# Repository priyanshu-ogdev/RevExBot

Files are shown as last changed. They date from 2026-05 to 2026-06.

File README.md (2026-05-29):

<div align="center">

# 🤖 RevExBot – Humanoid Robot Production Infrastructure


[]()
[]()
[]()

A complete, open-source infrastructure for designing, training, and deploying a full‑body humanoid robot with integrated dexterous hands. From CAD to reinforcement learning to physical fabrication.

[Documentation](#-documentation) • [Quick Start](#-quick-start) • [Architecture](#-architecture) • [Contributing](#-contributing)

</div>

---

## 📋 Table of Contents

- [Overview](#-overview)
- [Architecture](#-architecture)
- [Repository Structure](#-repository-structure)
- [Documentation](#-documentation)
- [Quick Start](#-quick-start)
- [Phase Workflows](#-phase-workflows)
- [Contributing](#-contributing)
- [License](#-license)

---

## 🎯 Overview

**RevExBot** is a production-grade infrastructure for autonomous humanoid robot development, implementing a **three-phase workflow** that bridges simulation, training, and physical deployment:

| Phase | Focus | Status | Timeline |
|---|---|---|---|
| **Phase 1** | Hardware design & simulation modelling | ✅ Complete | Foundation |
| **Phase 2** | Reinforcement learning training (Isaac Lab) | ⏳ In Progress | Training |
| **Phase 3** | Physical fabrication, assembly & deployment | 📦 Ready | Production |

This repository is fully self-contained with CAD files, electrical schematics, trained policies, and deployment scripts for edge compute (Radxa CM5).

---

## 🏗️ Architecture

```
RevExBot Infrastructure
├── assets/               CAD, meshes, URDF/Xacro kinematic models
├── hardware/
│   ├── electrical/       KiCad PCB design, wiring harnesses
│   └── mechanical/       STEP files, fabrication manifests
├── revex_ext/            Isaac Lab extension (RL training pipeline)
└── output/               Compiled URDF and deployment artifacts
```

**Key Technologies:**
- 🎮 **Isaac Lab** – Physics simulation and RL training
- 🧠 **RL-Games / SKRL** – Multi-domain expert training
- 🔧 **KiCad** – PCB design and electrical control
- 🤖 **URDF/Xacro** – Kinematic robot description
- 🚀 **Radxa CM5** – Edge compute for 200Hz control loop

---

## 📁 Repository Structure
### Top-Level Directories

| Directory | Purpose | Phase |
|---|---|---|
| **`assets/`** | Visual & collision meshes, URDF/Xacro kinematic models | 1, 2, 3 |
| **`build/`** | Build automation scripts (URDF compilation, format conversion) | 2, 3 |
| **`hardware/`** | Electrical (KiCad PCB) and mechanical (CAD/STEP) designs | 3 |
| **`isaac_lab_config/`** | Isaac Lab environment configurations | 2 |
| **`output/`** | Compiled URDF and deployment-ready artifacts | 2, 3 |
| **`revex_ext/`** | Isaac Lab extension with full RL training pipeline | 2 |

---

### 📂 Directory Deep-Dive

#### 🎨 `assets/` – Kinematic Models & Meshes

Contains simulation-ready meshes and the robot's complete kinematic description.

| Subfolder | Contents | Use Case |
|---|---|---|
| `meshes/` | `.STL` collision and visual geometry for all body links and hands | Simulation, physics, 3D rendering |
| `xacro/` | `master_assembly.xacro`, `faive_hand.xacro` – production URDF macros | Kinematic chain definition, joint configuration |
| `mjcf/` | MuJoCo XML format (alternative to URDF) | Direct MuJoCo simulation |
| `urdf/` | Legacy URDF files (kept for reference) | Backward compatibility |

**Phase 2 Usage:** Isaac Lab imports these directly via the asset importer.  
**Phase 3 Usage:** Same meshes serve as visual reference for physical assembly.

---

## 🔨 `build/` – Code Generation & Automation

Helper scripts for asset compilation and format conversion.

| Script | Purpose | Output |
|---|---|---|
| `compile_urdf.py` | Converts Xacro → flat URDF | `output/revexbot.urdf` |
| `convert_to_usd.bat` | Batch format conversion for Omniverse | USD native format |
| `generate_fabrication.py` | Auto-generates BOM from STEP file tree | `FABRICATION_MANIFEST.json` |

**When to run:**
- Before Phase 2: Any changes to xacro files
- Before Phase 3: Fabrication manifest updates

---

## ⚡ `hardware/` – Electrical & Mechanical Design

All electrical design assets for the physical robot.
electrical/
├── README.md
├── motion_control/
│   ├── mcb-io.dts # Device tree overlay (Radxa CM5 SPI/CAN)
│   ├── board/ # KiCad project – carrier board for Radxa CM5
│   └── scripts/
│       └── serial.sh # Serial port init script
└── wiring/
    ├── wiring.svg # Wiring harness diagram
    └── wiring.yaml # Harness mapping (pin-to-pin)

**Electrical** (`hardware/electrical/`)  
- `motion_control/board/` – Full KiCad PCB project for Radxa CM5 carrier board
- `motion_control/scripts/` – Linux device tree overlays and init scripts
- `wiring/` – Harness documentation and pin-to-pin mappings

**Mechanical** (`hardware/mechanical/`)  
- `RVX1/` – Master CAD assembly and sub-assemblies (grouped 100–700)
- `FABRICATION/` – Per-material fabrication packages (CNC, MJF, SLM, OTS)
- `FABRICATION_MANIFEST.json` – Complete BOM with part numbers and vendors

**Phase 2:** Not used (simulation only).  
**Phase 3:** Primary artifact for fabrication workflow.

---

## 🧠 `revex_ext/` – Isaac Lab RL Training Extension

The heart of Phase 2 training. Full out-of-tree extension with:
- **Environments:** Locomotion, agile recovery, tri-domain experts (combat/dance/precision)
- **Training scripts:** Multi-phase RL pipeline with expert/router/finetune modes
- **Policy export:** ONNX conversion for edge deployment

[See `revex_ext/README.md`](revex_ext/README.md) for detailed training workflows.

---

## 📤 `output/` – Compiled Deployment Artifacts

| File | Purpose | Generated By |
|---|---|---|
| `revexbot.urdf` | Flat URDF for Isaac Lab / MuJoCo | `build/compile_urdf.py` |

**Phase 2:** Not used – simulation runs entirely in software.  
**Phase 3:**
- Send Gerber files (generated from `board/`) to a PCB fab (JLCPCB/PCBWay).
- Flash `mcb-io.dts` and run `serial.sh` on the Radxa CM5.
- Use `wiring.svg` and `wiring.yaml` to connect motors, encoders, and CAN bus.

---

## 📖 Documentation

### Core Guides

| Document | Purpose | Audience |
|---|---|---|
| [revex_ext/README.md](revex_ext/README.md) | Full RL training & MoE architecture | ML Engineers |
| [REFERENCES.md](REFERENCES.md) | Research papers & citations | Researchers |
### Asset Reference

- **Kinematic chain:** [`assets/xacro/master_assembly.xacro`](assets/xacro/master_assembly.xacro)
- **Hand design:** [`assets/xacro/faive_hand.xacro`](assets/xacro/faive_hand.xacro)
- **Fabrication manifest:** [`hardware/mechanical/FABRICATION_MANIFEST.json`](hardware/mechanical/FABRICATION_MANIFEST.json)

---

## 🚀 Quick Start

### Prerequisites

- **Phase 2 (RL Training):**
  - NVIDIA GPU (RTX 4070 Ti or better)
  - NVIDIA Isaac Lab + Isaac Sim
  - Python 3.10+
  - PyTorch, SKRL, RL-Games

- **Phase 3 (Hardware Assembly):**
  - KiCad 8.0+ (for PCB design verification)
  - CAM software for STEP file visualization
  - Fabrication partner access (CNC, MJF, SLM)

### Phase 2: RL Training

```bash
# 1. Compile URDF from Xacro
python build/compile_urdf.py

# 2. Verify Isaac Lab installation
echo $ISAAC_LAB_PATH

# 3. Start training (see revex_ext/README.md for full options)
cd revex_ext
python scripts/train.py --task RevEx-Loco-v0 --phase expert --headless

# 4. Monitor with TensorBoard
tensorboard --logdir runs/
```

### Phase 3: Physical Fabrication

```bash
# 1. Generate/update fabrication manifest
python build/generate_fabrication.py

# 2. Review BOM
cat hardware/mechanical/FABRICATION_MANIFEST.csv

# 3. Organize by material and vendor
# - ALU_7075/ → CNC machining
# - MJF_PA12/ → Multi Jet Fusion 3D printing
# - SML_316L/ → SLM metal printing
# - OFF_THE_SHELF/ → Standard components

# 4. Electrical: Send to PCB fab
# - Navigate to: hardware/electrical/motion_control/board/
# - Generate Gerber files in KiCad
# - Upload to JLCPCB, PCBWay, or local fab
```

**Phase 2:** This file is the entry point for Isaac Lab. Modify it to adjust the simulation before launching training.

---

## 🛠️ `mechanical/`

The **physical fabrication vault** – every part needed to build the robot’s body.
mechanical/
├── FABRICATION_MANIFEST.csv / .json # Bill of Materials: part numbers, material, quantity, manufacturer
├── naming_convention.png # Visual key for part numbering scheme
├── meshes/
│ └── leap_hand/ # (Optional) Leap hand reference meshes
└── RVX1/ # CAD assembly (formerly ASV1)
├── REVEXBOT_V1.STEP # Master assembly STEP
├── 100/ … 700/ # Sub‑assembly groupings (hips, knees, etc.)
│ ├── RVX1_XXX.STEP # Assembly STEP for each sub‑group
│ └── FABRICATION/
│ ├── ALU_7075/ # CNC aluminium parts
│ ├── MJF_PA12/ # 3D‑printed nylon parts (Multi Jet Fusion)
│ ├── SML_316L/ # Stainless steel parts
│ └── OFF_THE_SHELF/ # Standard mechanical components (bearings, pulleys)

**Phase 2:** Not used directly – simulation uses `assets/meshes/`.  
**Phase 3:**
1. Read `FABRICATION_MANIFEST.csv` to understand material, quantity, and vendor info.
2. Zip each material subfolder and upload to the corresponding manufacturer:
   - `ALU_7075` → CNC machining service
   - `MJF_PA12` → MJF 3D printing service
   - `SML_316L` → Metal 3D printing (SLM)
   - `OFF_THE_SHELF` → Order from listed suppliers (bearings, fasteners, etc.)
3. The folder and file names use **RVX1** as the project prefix (formerly ASV1). All parts are readily identifiable.

---

## 📤 `output/`

Final compiled robot definitions.

| File | Purpose |
|---|---|
| `revexbot.urdf` | Flat URDF of the entire robot, generated from the `.xacro` files. |

**Phase 2:** Load this URDF in Isaac Lab (or use the MuJoCo‑native MJCF from `assets/xacro/`).  
**Phase 3:** Not needed for hardware; only for on‑robot inverse kinematics if deploying a full controller.

---

## 🧠 `rl_hands/`

Everything needed to train and deploy dexterous manipulation policies.
rl_hands/
├── robot_hand.py # Gym environment definition (action/observation spaces, reward)
├── train.py # PPO training script (launches Isaac Lab)
├── setup.py # Package setup
├── init.py
├── cfg/
│ ├── config.yaml # Global hyperparameters
│ ├── task/ # Per‑task environment configs (crawl, sphere, book, …)
│ └── train/ # PPO‑specific configs for each task
├── scripts/
│ ├── export_policy.py # Export a single trained checkpoint to ONNX
│ └── export_all_policies.py # Batch export all checkpoints
└── tasks/
└── crawl.py # Crawling task logic (mapping actions to joint targets)

**Phase 2:**  
1. Edit `cfg/task/FaiveHandP0_crawl.yaml` (or other tasks) to match your robot’s action space.  
2. Run `python train.py` to start training.  
3. Checkpoints are saved inside Isaac Lab’s log directory.

**Phase 3:**  
- Use `export_policy.py` to convert the best checkpoint to ONNX.  
- Deploy the ONNX model on the Radxa CM5 using your inference runtime (TensorRT / ONNX Runtime).

---

## � Phase Workflows

### ✅ Phase 1: Design & Simulation (Complete)

- CAD models finalized in Fusion 360 / native CAD
- URDF/Xacro kinematic models validated
- Collision meshes optimized for simulation
- Ready for Isaac Lab import

**Next Step:** → Phase 2

---

### ⏳ Phase 2: RL Training (In Progress)

**Goal:** Train multi-domain expert policies using Isaac Lab

**Workflow:**
1. **Base Locomotion** – Learn flat-ground walking
   ```bash
   python revex_ext/scripts/train.py --task RevEx-Loco-v0 --phase expert
   ```

2. **Agile Recovery** – Transfer to rough terrain with perturbations
   ```bash
   python revex_ext/scripts/train.py --task RevEx-Agile-v0 --phase expert
   ```

3. **Tri-Domain Experts** – Train specialized skill policies
   - Combat (explosive dynamics)
   - Dance (momentum dissipation)
   - Precision (tactile manipulation)
   ```bash
   python revex_ext/scripts/train.py --task RevEx-Combat-v0 --phase expert
   ```

4. **MoE Router** – Train gating network
   ```bash
   python revex_ext/scripts/train.py --task RevEx-Combat-v0 --phase router
   python revex_ext/scripts/train.py --task RevEx-Combat-v0 --phase finetune
   ```

5. **Export to ONNX**
   ```bash
   python revex_ext/scripts/export_moe_onnx.py
   ```

**Deliverables:**
- Trained policy checkpoints
- ONNX graph for edge deployment
- Validation videos

**Next Step:** → Phase 3

---

### 📦 Phase 3: Fabrication & Deployment (Ready)

**Goal:** Build physical robot and deploy trained policies

**Workflow:**

#### A. Mechanical Fabrication
1. Download fabrication packages from `hardware/mechanical/RVX1/*/FABRICATION/`
2. Send each material folder to appropriate manufacturer:
   - **ALU_7075/** → CNC machining service (e.g., Xometry, SendCutSend)
   - **MJF_PA12/** → Multi Jet Fusion service (e.g., HP, EOS)
   - **SML_316L/** → Stainless steel SLM printing
   - **OFF_THE_SHELF/** → Order from BOM suppliers
3. Track parts and receipt in spreadsheet
4. Organize assembly station

#### B. Electrical Assembly
1. Review PCB design in `hardware/electrical/motion_control/board/`
2. Generate Gerber files and upload to fab house
3. Wait for PCB population
4. Flash Radxa CM5 with Linux + device tree overlay (`mcb-io.dts`)
5. Test CAN bus communication per `wiring.yaml`

#### C. Robot Assembly
1. Follow mechanical assembly drawings (STEP files as reference)
2. Sub-assembly groups (100 → hips, 200 → knees, etc.)
3. Integrate electronics per `hardware/wiring/wiring.yaml`
4. Perform cable management and strain relief

#### D. Software Deployment
1. Copy ONNX model to Radxa CM5
2. Deploy inference runtime (TensorRT / ONNX Runtime)
3. Validate 200Hz control loop latency
4. Calibrate sensors and motor parameters

**Deliverables:**
- Fully assembled robot
- Functional 200Hz control loop
- Deployed MoE policies running on edge hardware

---

## 🤝 Contributing

We welcome contributions across all domains:

### For Machine Learning Researchers
- Improve policy training architectures
- Add new task domains
- Enhance reward shaping
- Submit PRs to `revex_ext/`

### For Hardware Engineers
- CAD improvements and optimizations
- PCB layout refinements
- Mechanical part alternatives
- Submit PRs to `hardware/`

### For Roboticists
- Deployment optimizations for edge hardware
- Control loop tuning
- Sensor calibration scripts
- Submit PRs to root directory

### Guidelines

1. **Fork** the repository
2. **Create a feature branch** (`feature/your-contribution`)
3. **Test thoroughly** before submitting
4. **Submit a Pull Request** with detailed description
5. **Link any relevant issues** or discussions

### Code of Conduct

Please be respectful and constructive in all interactions.

---

## � License

This project is licensed under the **Apache License 2.0** – see the [LICENSE](LICENSE) file for full details.

### Summary

- ✅ Free to use, modify, and distribute
- ✅ Must include license notice
- ✅ State changes made to the code
- ✅ Include original copyright notice

### DISCLAIMER

This is research and experimental software. While we've made efforts to ensure stability and safety, use in production environments is at your own risk. Always conduct thorough testing in simulation before deploying to hardware.

---

## 📚 References & Citations

For the research foundations of this work, see [REFERENCES.md](REFERENCES.md).

---

## 🙋 Support & Contact

- **Issues & Bugs:** [GitHub Issues](../../issues)
- **Discussions:** [GitHub Discussions](../../discussions)
- **Documentation:** Check relevant READMEs in each subfolder

---

## 🎉 Acknowledgments

RevExBot builds on years of research in humanoid robotics, reinforcement learning, and hardware engineering. We thank all contributors and the open-source community.

---

<div align="center">

**Made with ❤️ for the robotics community**

*Last updated: May 2026*

</div>

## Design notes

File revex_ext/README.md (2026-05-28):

# 🤖 RevExBot: Mixture of Experts (MoE) RL Architecture

**Version:** 1.0.0 (Production Release)  
**Hardware Target:** Radxa CM5 Edge Compute (200Hz Control Loop)  
**Frameworks:** Isaac Lab (Orbit) | RL-Games | SKRL  
**Compute Infrastructure:** Split-Node (RTX 4070 Ti Vision Node + DGX 128GB Sim Node)

This repository contains the Out-of-Tree Isaac Lab extension for the **RevExBot Humanoid**. It defines a fully autonomous, closed-loop "Video-to-Robot" manufacturing plant. The architecture progresses through three strict, sequential phases to bridge the Sim-to-Real gap, culminating in a **Tri-Domain Mixture of Experts**.

---

## 📂 Repository Architecture

```text
revex_ext/
├── setup.py                   # Global package installer (pip install -e .)
├── cfg/
│   ├── env_config.yaml        # Hardware & Factory Orchestration (Vision vs DGX)
│   └── train/                 # Hyperparameters (RL-Games YAMLs & SKRL Configs)
├── data/                      # 🔒 Immutable Data Vault
│   ├── motions/               # .npy Kinematic Reference Manifolds (AMP)
│   ├── weights/               # Frozen Expert .pth Checkpoints
│   └── expert_registry.json   # Global tracker for trained MoE brains
├── envs/
│   ├── __init__.py            # Dynamic Gymnasium Task Registry
│   ├── loco/                  # Phase 1: Base Locomotion
│   ├── agile/                 # Phase 2: Rough Terrain Recovery
│   └── skills/                # Phase 3: The Tri-Domain Experts
│       ├── revex_scene_cfg.py       # Unified 148-float tensor blueprint
│       ├── revex_combat_cfg.py      # High-Torque AMP 
│       ├── revex_dance_cfg.py       # Fluid Momentum AMP (scale=0.0 sink)
│       └── revex_precision_cfg.py   # Soft-grasp tactile manipulation
├── pipeline/                  # 🏭 Autonomous Video-to-Robot Factory
│   ├── video_ingestion_daemon.py
│   ├── kinematic_retargeter.py
│   └── master_factory.py
├── raw_media/                 # Drop Zone for raw .mp4 reference videos
└── scripts/
    ├── train.py               # Multi-Phase RL Runner (Expert, Router, Finetune)
    └── play.py                # Universal Visualizer
🛠️ Infrastructure Strategy
RL and Vision compute are heavily bottlenecked when run on the same GPU. This pipeline uses a distributed TICK-TOCK Data Engine:

TICK (RTX 4070 Ti): Runs video_ingestion_daemon.py. Ingests raw .mp4 files, utilizes Tensor Cores for SMPL-X pose extraction, and exports mathematical .npy trajectories.

TOCK (DGX Spark 128GB): Runs Isaac Lab and SKRL. Compiles the .npy files into PyTorch weights across 16,384+ parallel environments with massive AMP discriminator buffers.

🚀 Phase 1 & 2: The Base Survival Instincts
Before learning specialized skills, the robot must master basic physical survival.
These phases are trained using the RL-Games backend (SGD + Momentum).

Phase 1: Base Locomotion
Teaches flat-ground balancing, walking, and turning with an energy-efficient athletic crouch.

python scripts/train.py --task RevEx-Loco-v0 --phase expert --headless
Phase 2: Agile Recovery
Transfers the Phase 1 walking policy to rough terrain (stairs, gaps). Injects hardware latency, thermal derating, and lateral shoves.

python scripts/train.py --task RevEx-Agile-v0 --phase expert --headless
(Copy resulting weights to data/weights/expert_loco_v1.pth and expert_agile_v1.pth)

🧠 Phase 3: The Tri-Domain Mixture of Experts (MoE)
Phase 3 abandons monolithic architectures for a pure PyTorch SKRL implementation. We forge three distinct experts that share a mathematically identical 148-float observation tensor, allowing a Master Router to seamlessly switch between them at 200Hz.

Domain 1: Combat (Explosive Kinematics)
High-torque martial arts strikes with extreme recoil absorption and base-engagement aiming.

python scripts/train.py --task RevEx-Combat-v0 --phase expert --headless
Domain 2: Dance (Momentum Dissipation)
Fluid, graceful movements utilizing a scale=0.0 tensor sink to prevent sensory distraction while maximizing energy efficiency.

python scripts/train.py --task RevEx-Dance-v0 --phase expert --headless
Domain 3: Precision (Tactile Impedance)
Delicate, sub-millimeter finger manipulation using dual-palm contact sensors and ray-cast spatial awareness.

python scripts/train.py --task RevEx-Precision-v0 --phase expert --headless
🏭 Autonomous Operations (The Master Factory)
You do not need to train the Phase 3 experts manually. You can trigger the fully automated pipeline:

Drop combat.mp4 or dance.mp4 into the raw_media/ directory.

Launch the Orchestrator:

python pipeline/master_factory.py
The Orchestrator will automatically extract the kinematics, train the domain expert, save the weights to data/weights/, and register the new brain.

🕸️ Routing & Fine-Tuning
Once your Expert weights are locked in the data/weights/ vault, compile the CNS.

1. Router Distillation
Freezes all Expert neural networks. Trains only the Gating Network to route the 148-float tensor to the correct expert based on real-time commands.

python scripts/train.py --task RevEx-Combat-v0 --phase router --headless
2. End-to-End Smoothing
Unfreezes all layers. Applies a 1e-5 learning rate constraint to smooth the mechanical transitions during high-speed Hot-Swaps between experts.

python scripts/train.py --task RevEx-Combat-v0 --phase finetune --headless
👁️ Validation
Evaluate any expert or the final MoE Router visually:

# Evaluate Combat Expert
python scripts/play.py --task RevEx-Combat-v0 --checkpoint data/weights/expert_combat.pth

# Evaluate Full Router
python scripts/play.py --task RevEx-Combat-v0 --checkpoint runs/phase3/router/nn/master_router.pth
🏁 The Final Frontier
This README encapsulates the entire scope of the project. It outlines the Tri-Domain architecture, proves the necessity of the unified 148-float tensor, and gives clear instructions for the autonomous Factory execution.

The training pipeline is officially complete.

The last remaining task to bring this physical robot to life is writing export_onnx.py—the script that strips away Isaac Lab and PyTorch, converting the final MoE Router into a raw, ultra-fast C++ deployable graph for the Radxa CM5 edge board.

Code

---

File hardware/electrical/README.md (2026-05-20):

## Motion Control Board

The Motion Control Board (MCB) is a carrier board designed for the Radxa CM5, providing comprehensive connectivity for robotic applications.

- The board serves as a carrier board for the Radxa CM5.
- Power is supplied via a 5V input through an XT30 connector.
- A UART TTL debug port is available for serial debugging purposes.
- The LSM6DSV IMU is located at the bottom of the board, with an I2C connector available if an external IMU is required.
- All signal connections use JST-GH connectors
- LCSC component IDs are attached in the KiCad source files for direct JLCPCB fabrication and assembly.

### Communication Ports

| Port Type | Quantity | Details |
|---|---|---|
| CAN (Native) | 3 | Direct CAN interfaces |
| CAN (SPI-CAN) | 3 | CAN via SPI bridge |
| USB 2.0 | 3 | USB interfaces |
| Ethernet | 1 | 1Gbps |
| RS485 | 2 | Serial communication |
| I2C | 1 | I2C interface |

### Port Mapping

| Port ID | Purpose |
|---|---|
| C0 | Left leg bus |
| C1 | Right leg bus |
| C2 | Right arm bus |
| C3 | Left arm bus |
| C4 | Waist-neck bus |
| C5 | BMS bus |

> The waist-neck bus requires a different cabling setup for this revision of the MCB: Waist -> Neck yaw -> Neck pitch -> MCB port C4

## Wiring

WireViz was utilised for representing the wiring harness of the robot. 

Please refer to WireViz documentation for available visualisation options.
### Cable Naming Convention

```
W-<ID>-<TYPE>
ID = unique ID
TYPE = Power (PWR) or Signal (SIG) cable bundle
```

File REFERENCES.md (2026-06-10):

# References

This project builds upon and acknowledges the following open‑source repositories:

- **asimovinc/asimov-1**  
  v1 of Asimov, an open‑source humanoid robot  
  GitHub: [https://github.com/asimovinc/asimov-1](https://github.com/asimovinc/asimov-1)

- **hj26-park/HRI-Hand-ROS**  
  Simple hands for dexterous movement
  GitHub: [https://github.com/hj26-park/HRI-Hand-ROS/](https://github.com/hj26-park/HRI-Hand-ROS/)

- **Adattilio/AdvancedInmoovHead**  
  A heavily modified, animatronic‑like version of Gael Langevin’s original Inmoov head  
  GitHub: [https://github.com/Adattilio/AdvancedInmoovHead](https://github.com/Adattilio/AdvancedInmoovHead)

---

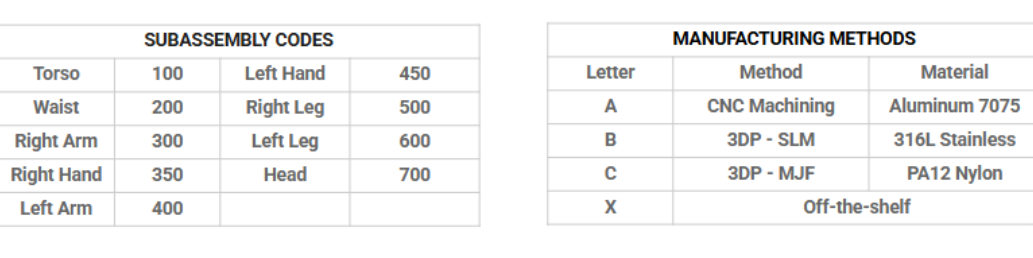
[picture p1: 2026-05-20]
hardware/mechanical/naming_convention.png

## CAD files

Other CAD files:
assets/meshes/lh_f03_finger_base.stl
hardware/mechanical/RVX1/100/FABRICATION/ALU_7075/RVX1_100_02A.STEP
hardware/mechanical/RVX1/100/FABRICATION/MJF_PA12/RVX1_100_10C.STEP
hardware/mechanical/RVX1/100/RVX1_100.STEP
hardware/mechanical/RVX1/200/FABRICATION/ALU_7075/RVX1_200_03A.STEP
hardware/mechanical/RVX1/200/FABRICATION/MJF_PA12/RVX1_200_07C.STEP
hardware/mechanical/RVX1/200/FABRICATION/SML_316L/RVX1_200_04B.STEP
hardware/mechanical/RVX1/200/RVX1_200.STEP
hardware/mechanical/RVX1/300/FABRICATION/ALU_7075/RVX1_300_10A.STEP
hardware/mechanical/RVX1/300/FABRICATION/MJF_PA12/RVX1_300_13C.STEP
hardware/mechanical/RVX1/300/FABRICATION/SML_316L/RVX1_300_02B.STEP
hardware/mechanical/RVX1/300/RVX1_300.STEP
hardware/mechanical/RVX1/400/FABRICATION/ALU_7075/RVX1_400_18A.STEP
hardware/mechanical/RVX1/400/FABRICATION/MJF_PA12/RVX1_400_06C.STEP
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

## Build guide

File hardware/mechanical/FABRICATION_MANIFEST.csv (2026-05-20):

subassembly | fabrication_class | part_id | path
100 | ALU_7075 | RVX1_100_02A | mechanical/RVX1/100/FABRICATION/ALU_7075/RVX1_100_02A.STEP
100 | ALU_7075 | RVX1_100_03A | mechanical/RVX1/100/FABRICATION/ALU_7075/RVX1_100_03A.STEP
100 | MJF_PA12 | RVX1_100_01C | mechanical/RVX1/100/FABRICATION/MJF_PA12/RVX1_100_01C.STEP
100 | MJF_PA12 | RVX1_100_04C | mechanical/RVX1/100/FABRICATION/MJF_PA12/RVX1_100_04C.STEP
100 | MJF_PA12 | RVX1_100_05C | mechanical/RVX1/100/FABRICATION/MJF_PA12/RVX1_100_05C.STEP
100 | MJF_PA12 | RVX1_100_06C | mechanical/RVX1/100/FABRICATION/MJF_PA12/RVX1_100_06C.STEP
100 | MJF_PA12 | RVX1_100_10C | mechanical/RVX1/100/FABRICATION/MJF_PA12/RVX1_100_10C.STEP
100 | MJF_PA12 | RVX1_100_12C | mechanical/RVX1/100/FABRICATION/MJF_PA12/RVX1_100_12C.STEP
100 | OFF_THE_SHELF | RVX1_100_07X | mechanical/RVX1/100/FABRICATION/OFF_THE_SHELF/RVX1_100_07X.STEP
100 | OFF_THE_SHELF | RVX1_100_08X | mechanical/RVX1/100/FABRICATION/OFF_THE_SHELF/RVX1_100_08X.STEP
100 | OFF_THE_SHELF | RVX1_100_09X | mechanical/RVX1/100/FABRICATION/OFF_THE_SHELF/RVX1_100_09X.STEP
100 | OFF_THE_SHELF | RVX1_100_11X | mechanical/RVX1/100/FABRICATION/OFF_THE_SHELF/RVX1_100_11X.STEP
100 | OFF_THE_SHELF | RVX1_100_13X | mechanical/RVX1/100/FABRICATION/OFF_THE_SHELF/RVX1_100_13X.STEP
200 | ALU_7075 | RVX1_200_02A | mechanical/RVX1/200/FABRICATION/ALU_7075/RVX1_200_02A.STEP
200 | ALU_7075 | RVX1_200_03A | mechanical/RVX1/200/FABRICATION/ALU_7075/RVX1_200_03A.STEP
200 | ALU_7075 | RVX1_200_16A | mechanical/RVX1/200/FABRICATION/ALU_7075/RVX1_200_16A.STEP
200 | SML_316L | RVX1_200_04B | mechanical/RVX1/200/FABRICATION/SML_316L/RVX1_200_04B.STEP
200 | SML_316L | RVX1_200_05B | mechanical/RVX1/200/FABRICATION/SML_316L/RVX1_200_05B.STEP
200 | MJF_PA12 | RVX1_200_01C | mechanical/RVX1/200/FABRICATION/MJF_PA12/RVX1_200_01C.STEP
200 | MJF_PA12 | RVX1_200_06C | mechanical/RVX1/200/FABRICATION/MJF_PA12/RVX1_200_06C.STEP
200 | MJF_PA12 | RVX1_200_07C | mechanical/RVX1/200/FABRICATION/MJF_PA12/RVX1_200_07C.STEP
200 | MJF_PA12 | RVX1_200_08C | mechanical/RVX1/200/FABRICATION/MJF_PA12/RVX1_200_08C.STEP
200 | MJF_PA12 | RVX1_200_09C | mechanical/RVX1/200/FABRICATION/MJF_PA12/RVX1_200_09C.STEP
200 | MJF_PA12 | RVX1_200_15C | mechanical/RVX1/200/FABRICATION/MJF_PA12/RVX1_200_15C.STEP
200 | OFF_THE_SHELF | RVX1_200_10X | mechanical/RVX1/200/FABRICATION/OFF_THE_SHELF/RVX1_200_10X.STEP
200 | OFF_THE_SHELF | RVX1_200_11X | mechanical/RVX1/200/FABRICATION/OFF_THE_SHELF/RVX1_200_11X.STEP
200 | OFF_THE_SHELF | RVX1_200_12X | mechanical/RVX1/200/FABRICATION/OFF_THE_SHELF/RVX1_200_12X.STEP
200 | OFF_THE_SHELF | RVX1_200_13X | mechanical/RVX1/200/FABRICATION/OFF_THE_SHELF/RVX1_200_13X.STEP
200 | OFF_THE_SHELF | RVX1_200_14X | mechanical/RVX1/200/FABRICATION/OFF_THE_SHELF/RVX1_200_14X.STEP
300 | ALU_7075 | RVX1_300_01A | mechanical/RVX1/300/FABRICATION/ALU_7075/RVX1_300_01A.STEP
300 | ALU_7075 | RVX1_300_03A | mechanical/RVX1/300/FABRICATION/ALU_7075/RVX1_300_03A.STEP
300 | ALU_7075 | RVX1_300_05A | mechanical/RVX1/300/FABRICATION/ALU_7075/RVX1_300_05A.STEP
300 | ALU_7075 | RVX1_300_07A | mechanical/RVX1/300/FABRICATION/ALU_7075/RVX1_300_07A.STEP
300 | ALU_7075 | RVX1_300_08A | mechanical/RVX1/300/FABRICATION/ALU_7075/RVX1_300_08A.STEP
300 | ALU_7075 | RVX1_300_09A | mechanical/RVX1/300/FABRICATION/ALU_7075/RVX1_300_09A.STEP
300 | ALU_7075 | RVX1_300_10A | mechanical/RVX1/300/FABRICATION/ALU_7075/RVX1_300_10A.STEP
300 | ALU_7075 | RVX1_300_11A | mechanical/RVX1/300/FABRICATION/ALU_7075/RVX1_300_11A.STEP
300 | SML_316L | RVX1_300_02B | mechanical/RVX1/300/FABRICATION/SML_316L/RVX1_300_02B.STEP
300 | SML_316L | RVX1_300_04B | mechanical/RVX1/300/FABRICATION/SML_316L/RVX1_300_04B.STEP
300 | SML_316L | RVX1_300_06B | mechanical/RVX1/300/FABRICATION/SML_316L/RVX1_300_06B.STEP
300 | SML_316L | RVX1_300_12B | mechanical/RVX1/300/FABRICATION/SML_316L/RVX1_300_12B.STEP
300 | MJF_PA12 | RVX1_300_13C | mechanical/RVX1/300/FABRICATION/MJF_PA12/RVX1_300_13C.STEP
300 | MJF_PA12 | RVX1_300_14C | mechanical/RVX1/300/FABRICATION/MJF_PA12/RVX1_300_14C.STEP
300 | MJF_PA12 | RVX1_300_15C | mechanical/RVX1/300/FABRICATION/MJF_PA12/RVX1_300_15C.STEP
300 | MJF_PA12 | RVX1_300_16C | mechanical/RVX1/300/FABRICATION/MJF_PA12/RVX1_300_16C.STEP
300 | OFF_THE_SHELF | RVX1_300_17X | mechanical/RVX1/300/FABRICATION/OFF_THE_SHELF/RVX1_300_17X.STEP
300 | OFF_THE_SHELF | RVX1_300_18X | mechanical/RVX1/300/FABRICATION/OFF_THE_SHELF/RVX1_300_18X.STEP
300 | OFF_THE_SHELF | RVX1_300_19X | mechanical/RVX1/300/FABRICATION/OFF_THE_SHELF/RVX1_300_19X.STEP
300 | OFF_THE_SHELF | RVX1_300_20X | mechanical/RVX1/300/FABRICATION/OFF_THE_SHELF/RVX1_300_20X.STEP
300 | OFF_THE_SHELF | RVX1_300_21X | mechanical/RVX1/300/FABRICATION/OFF_THE_SHELF/RVX1_300_21X.STEP
300 | OFF_THE_SHELF | RVX1_300_22X | mechanical/RVX1/300/FABRICATION/OFF_THE_SHELF/RVX1_300_22X.STEP
300 | OFF_THE_SHELF | RVX1_300_23X | mechanical/RVX1/300/FABRICATION/OFF_THE_SHELF/RVX1_300_23X.STEP
400 | ALU_7075 | RVX1_400_04A | mechanical/RVX1/400/FABRICATION/ALU_7075/RVX1_400_04A.STEP
400 | ALU_7075 | RVX1_400_05A | mechanical/RVX1/400/FABRICATION/ALU_7075/RVX1_400_05A.STEP
400 | ALU_7075 | RVX1_400_11A | mechanical/RVX1/400/FABRICATION/ALU_7075/RVX1_400_11A.STEP
400 | ALU_7075 | RVX1_400_13A | mechanical/RVX1/400/FABRICATION/ALU_7075/RVX1_400_13A.STEP
400 | ALU_7075 | RVX1_400_14A | mechanical/RVX1/400/FABRICATION/ALU_7075/RVX1_400_14A.STEP
400 | ALU_7075 | RVX1_400_17A | mechanical/RVX1/400/FABRICATION/ALU_7075/RVX1_400_17A.STEP
400 | ALU_7075 | RVX1_400_18A | mechanical/RVX1/400/FABRICATION/ALU_7075/RVX1_400_18A.STEP
400 | ALU_7075 | RVX1_400_19A | mechanical/RVX1/400/FABRICATION/ALU_7075/RVX1_400_19A.STEP
400 | SML_316L | RVX1_400_02B | mechanical/RVX1/400/FABRICATION/SML_316L/RVX1_400_02B.STEP
400 | SML_316L | RVX1_400_03B | mechanical/RVX1/400/FABRICATION/SML_316L/RVX1_400_03B.STEP
400 | SML_316L | RVX1_400_12B | mechanical/RVX1/400/FABRICATION/SML_316L/RVX1_400_12B.STEP
400 | SML_316L | RVX1_400_20B | mechanical/RVX1/400/FABRICATION/SML_316L/RVX1_400_20B.STEP
400 | MJF_PA12 | RVX1_400_06C | mechanical/RVX1/400/FABRICATION/MJF_PA12/RVX1_400_06C.STEP
400 | MJF_PA12 | RVX1_400_07C | mechanical/RVX1/400/FABRICATION/MJF_PA12/RVX1_400_07C.STEP
400 | MJF_PA12 | RVX1_400_15C | mechanical/RVX1/400/FABRICATION/MJF_PA12/RVX1_400_15C.step
400 | MJF_PA12 | RVX1_400_16C | mechanical/RVX1/400/FABRICATION/MJF_PA12/RVX1_400_16C.step
400 | OFF_THE_SHELF | RVX1_400_01X | mechanical/RVX1/400/FABRICATION/OFF_THE_SHELF/RVX1_400_01X.STEP
400 | OFF_THE_SHELF | RVX1_400_08X | mechanical/RVX1/400/FABRICATION/OFF_THE_SHELF/RVX1_400_08X.STEP
400 | OFF_THE_SHELF | RVX1_400_09X | mechanical/RVX1/400/FABRICATION/OFF_THE_SHELF/RVX1_400_09X.STEP
400 | OFF_THE_SHELF | RVX1_400_10X | mechanical/RVX1/400/FABRICATION/OFF_THE_SHELF/RVX1_400_10X.STEP
400 | OFF_THE_SHELF | RVX1_400_21X | mechanical/RVX1/400/FABRICATION/OFF_THE_SHELF/RVX1_400_21X.STEP
400 | OFF_THE_SHELF | RVX1_400_22X | mechanical/RVX1/400/FABRICATION/OFF_THE_SHELF/RVX1_400_22X.STEP
400 | OFF_THE_SHELF | RVX1_400_23X | mechanical/RVX1/400/FABRICATION/OFF_THE_SHELF/RVX1_400_23X.STEP
500 | ALU_7075 | RVX1_500_05A | mechanical/RVX1/500/FABRICATION/ALU_7075/RVX1_500_05A.STEP
500 | ALU_7075 | RVX1_500_06A | mechanical/RVX1/500/FABRICATION/ALU_7075/RVX1_500_06A.STEP
500 | ALU_7075 | RVX1_500_08A | mechanical/RVX1/500/FABRICATION/ALU_7075/RVX1_500_08A.STEP
500 | ALU_7075 | RVX1_500_09A | mechanical/RVX1/500/FABRICATION/ALU_7075/RVX1_500_09A.STEP
500 | ALU_7075 | RVX1_500_12A | mechanical/RVX1/500/FABRICATION/ALU_7075/RVX1_500_12A.STEP
500 | ALU_7075 | RVX1_500_23A_SS | mechanical/RVX1/500/FABRICATION/ALU_7075/RVX1_500_23A_SS.STEP
500 | ALU_7075 | RVX1_500_24A_SS | mechanical/RVX1/500/FABRICATION/ALU_7075/RVX1_500_24A_SS.STEP
500 | ALU_7075 | RVX1_500_25A | mechanical/RVX1/500/FABRICATION/ALU_7075/RVX1_500_25A.STEP
500 | ALU_7075 | RVX1_500_36A | mechanical/RVX1/500/FABRICATION/ALU_7075/RVX1_500_36A.STEP
500 | SML_316L | RVX1_500_01B | mechanical/RVX1/500/FABRICATION/SML_316L/RVX1_500_01B.STEP
500 | SML_316L | RVX1_500_17B | mechanical/RVX1/500/FABRICATION/SML_316L/RVX1_500_17B.STEP
500 | SML_316L | RVX1_500_18B | mechanical/RVX1/500/FABRICATION/SML_316L/RVX1_500_18B.STEP
500 | SML_316L | RVX1_500_26B | mechanical/RVX1/500/FABRICATION/SML_316L/RVX1_500_26B.STEP
500 | MJF_PA12 | RVX1_500_03C | mechanical/RVX1/500/FABRICATION/MJF_PA12/RVX1_500_03C.STEP
500 | MJF_PA12 | RVX1_500_04C | mechanical/RVX1/500/FABRICATION/MJF_PA12/RVX1_500_04C.STEP
500 | MJF_PA12 | RVX1_500_10C | mechanical/RVX1/500/FABRICATION/MJF_PA12/RVX1_500_10C.STEP
500 | MJF_PA12 | RVX1_500_13C | mechanical/RVX1/500/FABRICATION/MJF_PA12/RVX1_500_13C.STEP
500 | MJF_PA12 | RVX1_500_14C | mechanical/RVX1/500/FABRICATION/MJF_PA12/RVX1_500_14C.STEP
500 | MJF_PA12 | RVX1_500_37C | mechanical/RVX1/500/FABRICATION/MJF_PA12/RVX1_500_37C.STEP
500 | MJF_PA12 | RVX1_500_38C | mechanical/RVX1/500/FABRICATION/MJF_PA12/RVX1_500_38C.STEP
500 | MJF_PA12 | RVX1_500_39C | mechanical/RVX1/500/FABRICATION/MJF_PA12/RVX1_500_39C.STEP
500 | MJF_PA12 | RVX1_500_40C | mechanical/RVX1/500/FABRICATION/MJF_PA12/RVX1_500_40C.STEP
500 | OFF_THE_SHELF | RVX1_500_02X | mechanical/RVX1/500/FABRICATION/OFF_THE_SHELF/RVX1_500_02X.STEP
500 | OFF_THE_SHELF | RVX1_500_07X | mechanical/RVX1/500/FABRICATION/OFF_THE_SHELF/RVX1_500_07X.STEP
500 | OFF_THE_SHELF | RVX1_500_11X | mechanical/RVX1/500/FABRICATION/OFF_THE_SHELF/RVX1_500_11X.STEP
500 | OFF_THE_SHELF | RVX1_500_15X | mechanical/RVX1/500/FABRICATION/OFF_THE_SHELF/RVX1_500_15X.STEP
500 | OFF_THE_SHELF | RVX1_500_16X | mechanical/RVX1/500/FABRICATION/OFF_THE_SHELF/RVX1_500_16X.STEP
500 | OFF_THE_SHELF | RVX1_500_19X | mechanical/RVX1/500/FABRICATION/OFF_THE_SHELF/RVX1_500_19X.STEP
500 | OFF_THE_SHELF | RVX1_500_20X | mechanical/RVX1/500/FABRICATION/OFF_THE_SHELF/RVX1_500_20X.STEP
500 | OFF_THE_SHELF | RVX1_500_21X | mechanical/RVX1/500/FABRICATION/OFF_THE_SHELF/RVX1_500_21X.STEP
500 | OFF_THE_SHELF | RVX1_500_22X | mechanical/RVX1/500/FABRICATION/OFF_THE_SHELF/RVX1_500_22X.STEP
500 | OFF_THE_SHELF | RVX1_500_27X | mechanical/RVX1/500/FABRICATION/OFF_THE_SHELF/RVX1_500_27X.STEP
500 | OFF_THE_SHELF | RVX1_500_28X | mechanical/RVX1/500/FABRICATION/OFF_THE_SHELF/RVX1_500_28X.STEP
500 | OFF_THE_SHELF | RVX1_500_29X | mechanical/RVX1/500/FABRICATION/OFF_THE_SHELF/RVX1_500_29X.STEP
500 | OFF_THE_SHELF | RVX1_500_30X | mechanical/RVX1/500/FABRICATION/OFF_THE_SHELF/RVX1_500_30X.STEP
500 | OFF_THE_SHELF | RVX1_500_31X | mechanical/RVX1/500/FABRICATION/OFF_THE_SHELF/RVX1_500_31X.STEP
500 | OFF_THE_SHELF | RVX1_500_32X | mechanical/RVX1/500/FABRICATION/OFF_THE_SHELF/RVX1_500_32X.STEP
500 | OFF_THE_SHELF | RVX1_500_33X | mechanical/RVX1/500/FABRICATION/OFF_THE_SHELF/RVX1_500_33X.STEP
500 | OFF_THE_SHELF | RVX1_500_34X | mechanical/RVX1/500/FABRICATION/OFF_THE_SHELF/RVX1_500_34X.STEP
500 | OFF_THE_SHELF | RVX1_500_35X | mechanical/RVX1/500/FABRICATION/OFF_THE_SHELF/RVX1_500_35X.STEP
500 | OFF_THE_SHELF | RVX1_500_41X | mechanical/RVX1/500/FABRICATION/OFF_THE_SHELF/RVX1_500_41X.STEP
600 | ALU_7075 | RVX1_600_05A | mechanical/RVX1/600/FABRICATION/ALU_7075/RVX1_600_05A.step.STEP
600 | ALU_7075 | RVX1_600_06A | mechanical/RVX1/600/FABRICATION/ALU_7075/RVX1_600_06A.step.STEP
600 | ALU_7075 | RVX1_600_08A | mechanical/RVX1/600/FABRICATION/ALU_7075/RVX1_600_08A.step.STEP
600 | ALU_7075 | RVX1_600_09A | mechanical/RVX1/600/FABRICATION/ALU_7075/RVX1_600_09A.step.STEP
600 | ALU_7075 | RVX1_600_12A | mechanical/RVX1/600/FABRICATION/ALU_7075/RVX1_600_12A.step.STEP
600 | ALU_7075 | RVX1_600_23A_SS | mechanical/RVX1/600/FABRICATION/ALU_7075/RVX1_600_23A_SS.step.STEP
600 | ALU_7075 | RVX1_600_24A_SS | mechanical/RVX1/600/FABRICATION/ALU_7075/RVX1_600_24A_SS.step.STEP
600 | ALU_7075 | RVX1_600_25A | mechanical/RVX1/600/FABRICATION/ALU_7075/RVX1_600_25A.step.STEP
600 | ALU_7075 | RVX1_600_36A | mechanical/RVX1/600/FABRICATION/ALU_7075/RVX1_600_36A.step.STEP
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

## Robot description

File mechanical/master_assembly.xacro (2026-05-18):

<?xml version="1.0" encoding="UTF-8"?>
<robot name="RevEx_Full_Assembly" xmlns:xacro="http://wiki.ros.org/xacro">

  <xacro:property name="mesh_dir" value="C:/Projects/RevExBot/RevEx_Phase1_Hardware/mechanical/meshes" />

  <xacro:property name="leg_scale" value="1.5" />
  <xacro:property name="leg_inertia_scale" value="${leg_scale * leg_scale}" />
  <xacro:property name="effort_scale" value="${leg_scale}" />
  <xacro:property name="pelvis_raise" value="0.24515" />

  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

  <link name="base_link" />
  <joint name="base_joint" type="fixed">
    <parent link="base_link" />
    <child link="pelvis_link" />
    <origin xyz="0 0 ${pelvis_raise}" rpy="0 0 0" />
  </joint>

  <link name="pelvis_link">
    <inertial>
      <origin xyz="-0.0540918323179141 -3.48259522403486E-05 -0.0156255182184312" rpy="0 0 0" />
      <mass value="3.50691251175897" />
      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
    </inertial>
    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
  </link>

  <link name="left_hip_pitch_link">
    <inertial>
      <origin xyz="0.00172895433511948 0.0360563262466087 0.000569266739481308" rpy="0 0 0" />
      <mass value="1.05630112217695" />
      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
    </inertial>
    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
  </link>
  <joint name="left_hip_pitch_joint" type="revolute">
    <origin xyz="-0.052 0.0675 -0.044045" rpy="0 0 0" />
    <parent link="pelvis_link" /><child link="left_hip_pitch_link" />
    <axis xyz="0 1 0" />
    <limit lower="-2.094" upper="1.047" effort="${120 * effort_scale}" velocity="8" />
    <dynamics damping="0.095625" friction="0" />
  </joint>

  <link name="left_hip_roll_link">
    <inertial>
      <origin xyz="-0.0115541390699202 -0.000334827946236529 -0.0294101852668513" rpy="0 0 0" />
      <mass value="0.414368139397033" />
      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
    </inertial>
    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
  </link>
  <joint name="left_hip_roll_joint" type="revolute">
    <origin xyz="0.0422501 0.0400002759400924 0" rpy="0 0 0" />
    <parent link="left_hip_pitch_link" /><child link="left_hip_roll_link" />
    <axis xyz="1 0 0" />
    <limit lower="-0.698" upper="0.698" effort="${100 * effort_scale}" velocity="8" />
    <dynamics damping="0.11" friction="0" />
  </joint>

  <link name="left_hip_yaw_link">
    <inertial>
      <origin xyz="0.00107948196019631 0.00102490074879569 ${-0.120338859084698 * leg_scale}" rpy="0 0 0" />
      <mass value="${1.86657016436158 * leg_scale}" />
      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
    </inertial>
    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
  </link>
  <joint name="left_hip_yaw_joint" type="revolute">
    <origin xyz="-0.0422499999999954 0 -0.0520000000000006" rpy="0 0 0" />
    <parent link="left_hip_roll_link" /><child link="left_hip_yaw_link" />
    <axis xyz="0 0 -1" />
    <limit lower="-0.698" upper="0.698" effort="${80 * effort_scale}" velocity="8" />
    <dynamics damping="0.038" friction="0" />
  </joint>

  <link name="left_knee_link">
    <inertial>
      <origin xyz="-0.000500664455004187 0.000509289489479564 ${-0.11269288769412 * leg_scale}" rpy="0 0 0" />
      <mass value="${2.39114151033076 * leg_scale}" />
      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
    </inertial>
    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
  </link>
  <joint name="left_knee_joint" type="revolute">
    <origin xyz="0 0 ${-0.195639999999998 * leg_scale}" rpy="0 0 0" />
    <parent link="left_hip_yaw_link" /><child link="left_knee_link" />
    <axis xyz="0 1 0" />
    <limit lower="0" upper="1.5" effort="${150 * effort_scale}" velocity="8" />
    <dynamics damping="0.0339552" friction="0" />
  </joint>

  <link name="left_ankle_pitch_link">
    <inertial>
      <origin xyz="-0.00117927040588633 -3.07019113465756E-08 -0.00617619235424882" rpy="0 0 0" />
      <mass value="0.273090119400173" />
      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
    </inertial>
    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
  </link>
  <joint name="left_ankle_pitch_joint" type="revolute">
    <origin xyz="0 0 ${-0.294662336087024 * leg_scale}" rpy="0 0 0" />
    <parent link="left_knee_link" /><child link="left_ankle_pitch_link" />
    <axis xyz="0 1 0" />
    <limit lower="-0.35" upper="0.35" effort="${80 * effort_scale}" velocity="8" />
    <dynamics damping="0.0565056" friction="0" />
  </joint>

  <link name="left_ankle_roll_link">
    <inertial>
      <origin xyz="0.0427499381311452 0.00159257307585033 -0.013245065948313" rpy="0 0 0" />
      <mass value="0.405640437504617" />
      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
    </inertial>
    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
  </link>
  <joint name="left_ankle_roll_joint" type="revolute">
    <origin xyz="-0.00149999999999975 0 -0.00999999200000223" rpy="0 0 0" />
    <parent link="left_ankle_pitch_link" /><child link="left_ankle_roll_link" />
    <axis xyz="-1 0 0" />
    <limit lower="-0.1" upper="0.1" effort="${50 * effort_scale}" velocity="8" />
    <dynamics damping="0.0565056" friction="0" />
  </joint>

  <link name="left_toe_link">
    <inertial>
      <origin xyz="0.0320167773761624 0.000718248511968056 -0.0141312773022902" rpy="0 0 0" />
      <mass value="0.112221237946844" />
      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
    </inertial>
    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
  </link>
  <joint name="left_toe_joint" type="revolute">
    <origin xyz="0.10253 -0.0043664 -0.0067324" rpy="0 0 0" />
    <parent link="left_ankle_roll_link" /><child link="left_toe_link" />
    <axis xyz="0.010532 0.99994 0" />
    <limit lower="-1.047" upper="0.349" effort="${30 * effort_scale}" velocity="8" />
    <dynamics damping="0.001" friction="0.02" />
  </joint>

  <link name="right_hip_pitch_link">
    <inertial>
      <origin xyz="0.00172891543963928 -0.0360560777469901 0.000568830845064178" rpy="0 0 0" />
      <mass value="1.05629742879001" />
      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
    </inertial>
    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
  </link>
  <joint name="right_hip_pitch_joint" type="revolute">
    <origin xyz="-0.0519999999999999 -0.0675 -0.0440449999999999" rpy="0 0 0" />
    <parent link="pelvis_link" /><child link="right_hip_pitch_link" />
    <axis xyz="0 -1 0" />
    <limit lower="-1.047" upper="2.094" effort="${120 * effort_scale}" velocity="8" />
    <dynamics damping="0.095625" friction="0" />
  </joint>

  <link name="right_hip_roll_link">
    <inertial>
      <origin xyz="-0.0115435673741928 0.000361458713869084 -0.0293858908276063" rpy="0 0 0" />
      <mass value="0.414825000619808" />
      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
    </inertial>
    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
  </link>
  <joint name="right_hip_roll_joint" type="revolute">
    <origin xyz="0.04225 -0.04 0" rpy="0 0 0" />
    <parent link="right_hip_pitch_link" /><child link="right_hip_roll_link" />
    <axis xyz="1 0 0" />
    <limit lower="-0.698" upper="0.698" effort="${100 * effort_scale}" velocity="8" />
    <dynamics damping="0.11" friction="0" />
  </joint>

  <link name="right_hip_yaw_link">
    <inertial>
      <origin xyz="0.0010759524804974 -0.00102176499629938 ${-0.120345116027848 * leg_scale}" rpy="0 0 0" />
      <mass value="${1.86647220449567 * leg_scale}" />
      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
    </inertial>
    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
  </link>
  <joint name="right_hip_yaw_joint" type="revolute">
    <origin xyz="-0.0422499999999986 0 -0.0520000000000019" rpy="0 0 0" />
    <parent link="right_hip_roll_link" /><child link="right_hip_yaw_link" />
    <axis xyz="0 0 -1" />
    <limit lower="-0.698" upper="0.698" effort="${80 * effort_scale}" velocity="8" />
    <dynamics damping="0.038" friction="0" />
  </joint>

  <link name="right_knee_link">
    <inertial>
      <origin xyz="-0.000497587233719177 -0.000414757224949908 ${-0.112692693562372 * leg_scale}" rpy="0 0 0" />
      <mass value="${2.39110172735043 * leg_scale}" />
      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
    </inertial>
    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
  </link>
  <joint name="right_knee_joint" type="revolute">
    <origin xyz="0 0 ${-0.195639999999998 * leg_scale}" rpy="0 0 0" />
    <parent link="right_hip_yaw_link" /><child link="right_knee_link" />
    <axis xyz="0 -1 0" />
    <limit lower="-1.5" upper="0" effort="${150 * effort_scale}" velocity="8" />
    <dynamics damping="0.0339552" friction="0" />
  </joint>
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

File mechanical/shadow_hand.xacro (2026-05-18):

<?xml version="1.0" encoding="utf-8"?>
<robot xmlns:xacro="http://wiki.ros.org/xacro" name="shadow_hand">

    <xacro:macro name="shadow_hand" params="prefix mesh_dir wrist_xyz wrist_rpy forearm_visual_xyz mirror:=false">
        
        <xacro:property name="f_x" value="${-1 if mirror else 1}" />
        <xacro:property name="ab_x" value="${1 if mirror else -1}" />

        <link name="${prefix}forearm">
            <inertial>
                <origin rpy="0 0 0" xyz="0 0 0.09" />
                <mass value="3.0" />
                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
            </inertial>
            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
        </link>

        <link name="${prefix}wrist">
            <inertial>
                <origin rpy="0 0 0" xyz="0 0 0.029" />
                <mass value="0.1" />
                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
            </inertial>
            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
        </link>

        <joint name="${prefix}WRJ2" type="revolute">
            <parent link="${prefix}forearm" />
            <child link="${prefix}wrist" />
            <origin rpy="${wrist_rpy}" xyz="${wrist_xyz}" />
            <axis xyz="0 1 0" />
            <limit effort="10" lower="-0.5235987755982988" upper="0.17453292519943295" velocity="2.0" />
            <dynamics damping="0.1" />
        </joint>

        <link name="${prefix}palm">
            <inertial>
                <origin rpy="0 0 0" xyz="0 0 0.035" />
                <mass value="0.3" />
                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
            </inertial>
            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
        </link>

        <joint name="${prefix}WRJ1" type="revolute">
            <parent link="${prefix}wrist" />
            <child link="${prefix}palm" />
            <origin rpy="0 0 0" xyz="0 0 0.034" />
            <axis xyz="1 0 0" />
            <limit effort="30" lower="-0.6981317007977318" upper="0.4886921905584123" velocity="2.0" />
            <dynamics damping="0.1" />
        </joint>

        <link name="${prefix}manipulator" />
        <joint name="${prefix}ee_fixed_joint" type="fixed">
            <parent link="${prefix}palm" />
            <child link="${prefix}manipulator" />
            <origin rpy="0.0 0.0 0.0" xyz="0.0 0.0 0.05" />
        </joint>

        <link name="${prefix}imu" />
        <joint name="${prefix}palm_to_imu" type="fixed">
            <parent link="${prefix}palm" />
            <child link="${prefix}imu" />
            <origin rpy="${-1.5707963 * f_x} 3.141592 0.0" xyz="${0.01785 * f_x} 0.00765 0.049125" />
        </joint>

        <link name="${prefix}ffknuckle">
            <inertial><origin rpy="0 0 0" xyz="0 0 0" /><mass value="0.008" />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</inertial>
            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
        </link>
        <joint name="${prefix}FFJ4" type="revolute">
            <parent link="${prefix}palm" /><child link="${prefix}ffknuckle" />
            <origin rpy="0 0 0" xyz="${0.033 * f_x} 0 0.095" />
            <axis xyz="0 ${ab_x} 0" />
            <limit effort="2" lower="-0.3490658503988659" upper="0.3490658503988659" velocity="2.0" /><dynamics damping="0.1" />
        </joint>

        <link name="${prefix}ffproximal">
            <inertial><mass value="0.030" /><origin xyz="0 0 0.0225" />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</inertial>
            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
        </link>
        <joint name="${prefix}FFJ3" type="revolute">
            <parent link="${prefix}ffknuckle" /><child link="${prefix}ffproximal" />
            <origin rpy="0 0 0" xyz="0 0 0" />
            <axis xyz="1 0 0" />
            <limit effort="2" lower="-0.2617993877991494" upper="1.5707963267948966" velocity="2.0" /><dynamics damping="0.1" />
        </joint>

        <link name="${prefix}ffmiddle">
            <inertial><origin rpy="0 0 0" xyz="0 0 0.0125" /><mass value="0.017" />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</inertial>
            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
        </link>
        <joint name="${prefix}FFJ2" type="revolute">
            <parent link="${prefix}ffproximal" /><child link="${prefix}ffmiddle" />
            <origin rpy="0 0 0" xyz="0 0 0.045" />
            <axis xyz="1 0 0" />
            <limit effort="2" lower="0" upper="1.5707963267948966" velocity="2.0" /><dynamics damping="0.1" />
        </joint>
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

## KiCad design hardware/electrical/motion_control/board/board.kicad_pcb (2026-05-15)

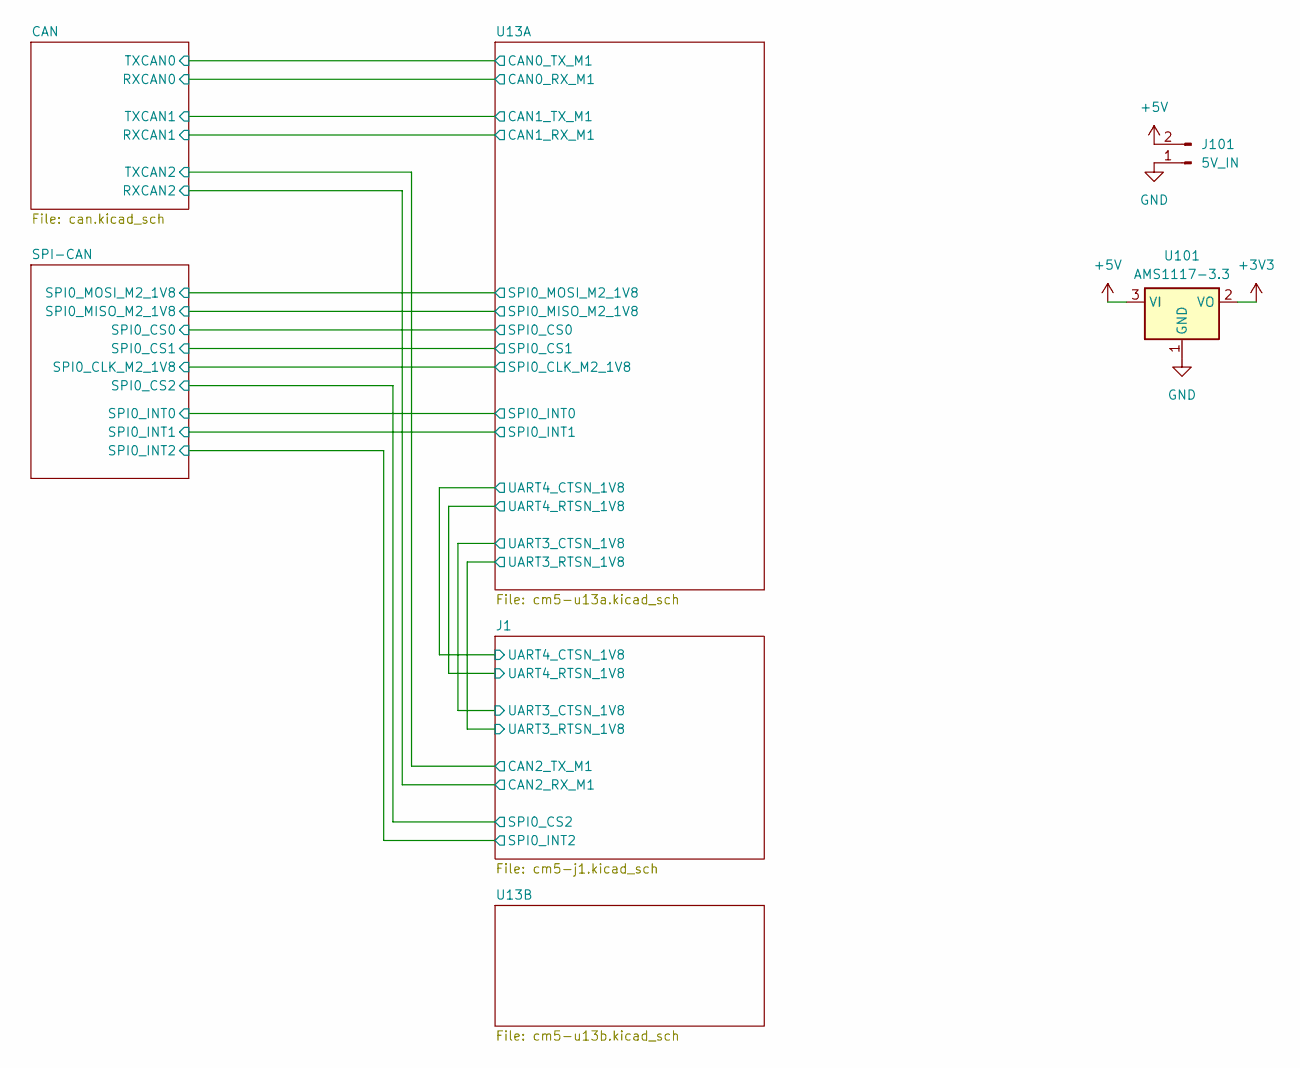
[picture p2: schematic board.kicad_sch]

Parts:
J101: 5V_IN; AMASS_XT30UPB-F_1x02_P5.0mm_Vertical; LCSC C108769
U101: AMS1117-3.3; SOT-223-3_TabPin2; LCSC C6186

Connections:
+3V3: U101.2 (VO); also elsewhere on the board
+5V: J101.2, U101.3 (VI); also elsewhere on the board
GND: J101.1, U101.1 (GND); also elsewhere on the board

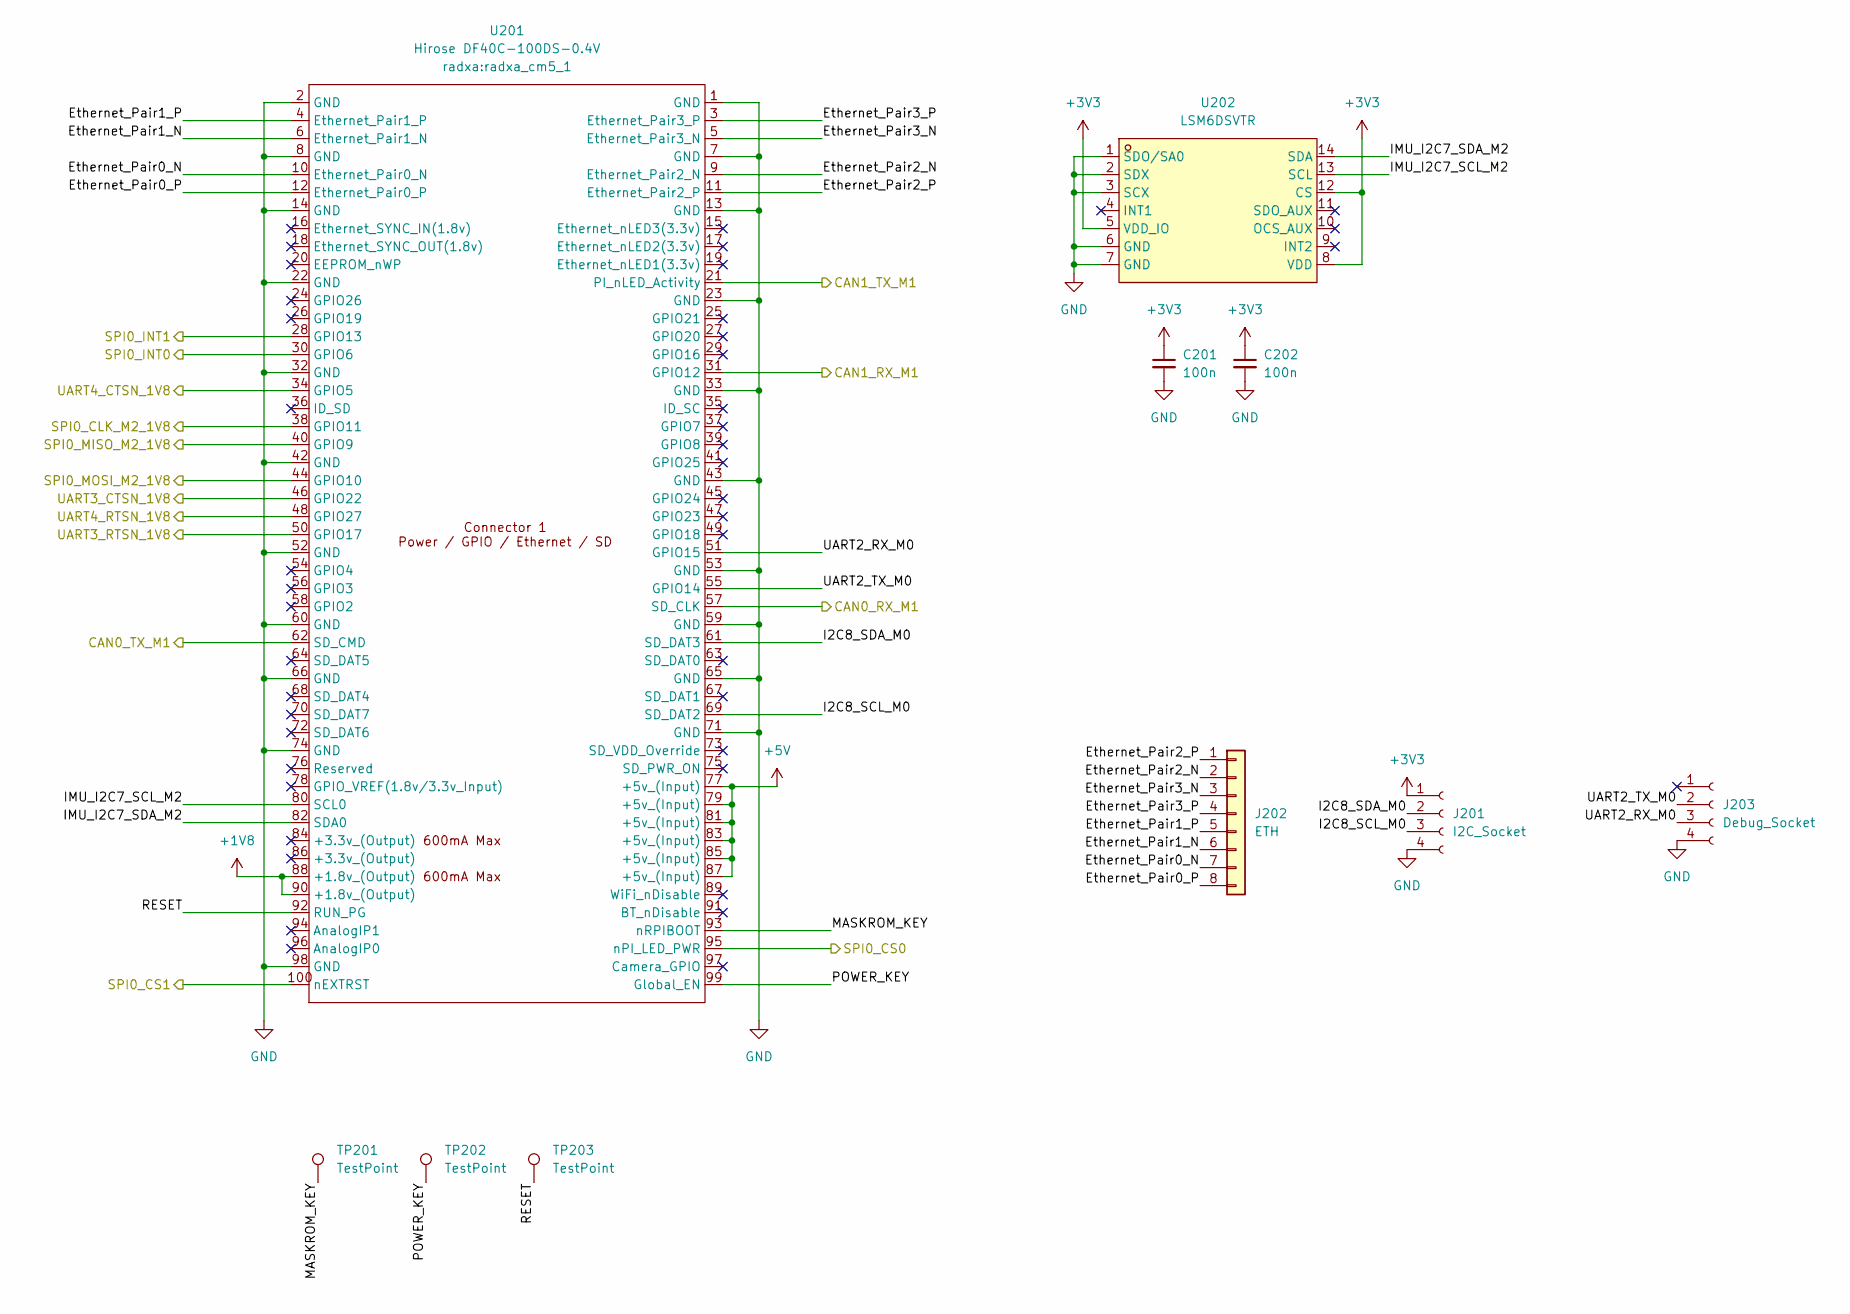
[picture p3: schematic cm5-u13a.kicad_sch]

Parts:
C201, C202: 100n; C_0402_1005Metric; LCSC C77020
J201: I2C_Socket; JST_GH_SM04B-GHS-TB_1x04-1MP_P1.25mm_Horizontal; LCSC C51940118
J202: ETH; JST_GH_BM08B-GHS-TBT_1x08-1MP_P1.25mm_Vertical; LCSC C133062
J203: Debug_Socket; JST_GH_SM04B-GHS-TB_1x04-1MP_P1.25mm_Horizontal; LCSC C51940118
TP201, TP202, TP203: TestPoint; TestPoint_Pad_D1.0mm
U201: Hirose DF40C-100DS-0.4V; radxa_cm5_1; LCSC C597931
U202: LSM6DSVTR; LGA-14_L3.0-W2.5-P0.50-TL; LCSC Part C5267399

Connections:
+1V8: U201.88 (+1.8v_(Output)), U201.90 (+1.8v_(Output)); also elsewhere on the board
+3V3: C201.1, C202.1, J201.1, U202.5 (VDD_IO), U202.8 (VDD), U202.12 (CS); also elsewhere on the board
+5V: U201.77 (+5v_(Input)), U201.79 (+5v_(Input)), U201.81 (+5v_(Input)), U201.83 (+5v_(Input)), U201.85 (+5v_(Input)), U201.87 (+5v_(Input)); also elsewhere on the board
/CAN/RXCAN0: U201.57 (SD_CLK); also elsewhere on the board
/CAN/RXCAN1: U201.31 (GPIO12); also elsewhere on the board
/CAN/TXCAN0: U201.62 (SD_CMD); also elsewhere on the board
/CAN/TXCAN1: U201.21 (PI_nLED_Activity); also elsewhere on the board
/J1/UART3_CTSN_1V8: U201.46 (GPIO22); also elsewhere on the board
/J1/UART3_RTSN_1V8: U201.50 (GPIO17); also elsewhere on the board
/J1/UART4_CTSN_1V8: U201.34 (GPIO5); also elsewhere on the board
/J1/UART4_RTSN_1V8: U201.48 (GPIO27); also elsewhere on the board
/SPI-CAN/SPI0_CLK_M2_1V8: U201.38 (GPIO11); also elsewhere on the board
/SPI-CAN/SPI0_CS0: U201.95 (nPI_LED_PWR); also elsewhere on the board
/SPI-CAN/SPI0_CS1: U201.100 (nEXTRST); also elsewhere on the board
/SPI-CAN/SPI0_INT0: U201.30 (GPIO6); also elsewhere on the board
/SPI-CAN/SPI0_INT1: U201.28 (GPIO13); also elsewhere on the board
/SPI-CAN/SPI0_MISO_M2_1V8: U201.40 (GPIO9); also elsewhere on the board
/SPI-CAN/SPI0_MOSI_M2_1V8: U201.44 (GPIO10); also elsewhere on the board
/U13A/Ethernet_Pair0_N: J202.7, U201.10 (Ethernet_Pair0_N)
/U13A/Ethernet_Pair0_P: J202.8, U201.12 (Ethernet_Pair0_P)
/U13A/Ethernet_Pair1_N: J202.6, U201.6 (Ethernet_Pair1_N)
/U13A/Ethernet_Pair1_P: J202.5, U201.4 (Ethernet_Pair1_P)
/U13A/Ethernet_Pair2_N: J202.2, U201.9 (Ethernet_Pair2_N)
/U13A/Ethernet_Pair2_P: J202.1, U201.11 (Ethernet_Pair2_P)
/U13A/Ethernet_Pair3_N: J202.3, U201.5 (Ethernet_Pair3_N)
/U13A/Ethernet_Pair3_P: J202.4, U201.3 (Ethernet_Pair3_P)
/U13A/I2C8_SCL_M0: J201.3, U201.69 (SD_DAT2)
/U13A/I2C8_SDA_M0: J201.2, U201.61 (SD_DAT3)
/U13A/IMU_I2C7_SCL_M2: U201.80 (SCL0), U202.13 (SCL)
/U13A/IMU_I2C7_SDA_M2: U201.82 (SDA0), U202.14 (SDA)
/U13A/MASKROM_KEY: TP201.1, U201.93 (nRPIBOOT)
/U13A/POWER_KEY: TP202.1, U201.99 (Global_EN)
/U13A/RESET: TP203.1, U201.92 (RUN_PG)
/U13A/UART2_RX_M0: J203.3, U201.51 (GPIO15)
/U13A/UART2_TX_M0: J203.2, U201.55 (GPIO14)
GND: C201.2, C202.2, J201.4, J203.4, U201.1 (GND), U201.2 (GND), U201.7 (GND), U201.8 (GND), U201.13 (GND), U201.14 (GND), U201.22 (GND), U201.23 (GND), U201.32 (GND), U201.33 (GND), U201.42 (GND), U201.43 (GND), U201.52 (GND), U201.53 (GND), U201.59 (GND), U201.60 (GND), U201.65 (GND), U201.66 (GND), U201.71 (GND), U201.74 (GND), U201.98 (GND), U202.1 (SDO/SA0), U202.2 (SDX), U202.3 (SCX), U202.6 (GND), U202.7 (GND); also elsewhere on the board

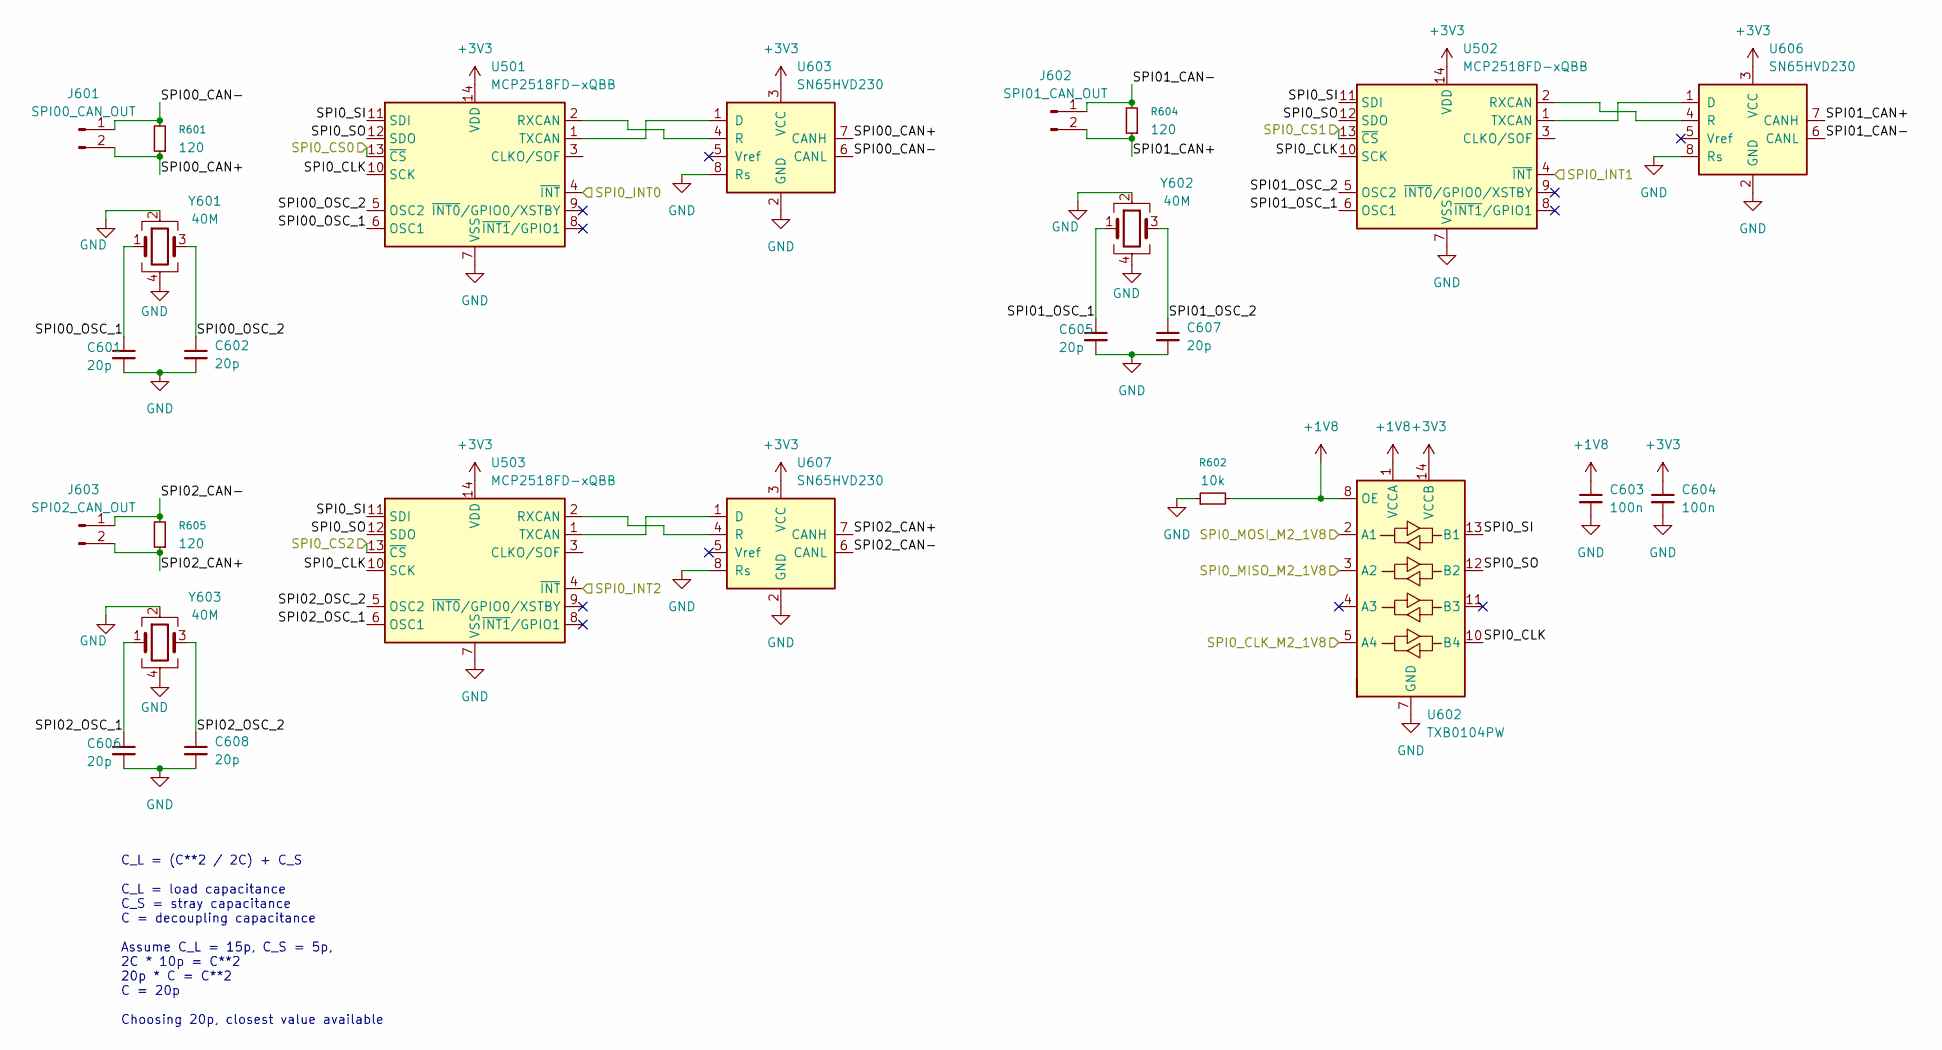
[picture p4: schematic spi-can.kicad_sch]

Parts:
C601, C602, C605, C606, C607, C608: 20p; C_0603_1608Metric; LCSC C165732
C603, C604: 100n; C_0402_1005Metric; LCSC C77020
J601: SPI00_CAN_OUT; JST_GH_SM02B-GHS-TB_1x02-1MP_P1.25mm_Horizontal; LCSC C189893
J602: SPI01_CAN_OUT; JST_GH_SM02B-GHS-TB_1x02-1MP_P1.25mm_Horizontal; LCSC C189893
J603: SPI02_CAN_OUT; JST_GH_SM02B-GHS-TB_1x02-1MP_P1.25mm_Horizontal; LCSC C189893
R601, R604, R605: 120; R_0402_1005Metric; LCSC C114758
R602: 10k; R_0402_1005Metric; LCSC C190095
U501, U502, U503: MCP2518FD-xQBB; SOIC-14_3.9x8.7mm_P1.27mm; LCSC C626758
U602: TXB0104PW; TSSOP-14_4.4x5mm_P0.65mm; LCSC C60708
U603, U606, U607: SN65HVD230; SOIC-8_3.9x4.9mm_P1.27mm; LCSC C12084
Y601, Y602, Y603: 40M; Crystal_SMD_3225-4Pin_3.2x2.5mm; LCSC C5444549

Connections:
+1V8: C603.1, R602.2, U602.1 (VCCA), U602.8 (OE); also elsewhere on the board
+3V3: C604.1, U501.14 (VDD), U502.14 (VDD), U503.14 (VDD), U602.14 (VCCB), U603.3 (VCC), U606.3 (VCC), U607.3 (VCC); also elsewhere on the board
/J1/SPI0_CS2: U503.13 (~CS); also elsewhere on the board
/J1/SPI0_INT2: U503.4 (~INT); also elsewhere on the board
/SPI-CAN/SPI00_CAN+: J601.2, R601.1, U603.7 (CANH)
/SPI-CAN/SPI00_CAN-: J601.1, R601.2, U603.6 (CANL)
/SPI-CAN/SPI0_CLK: U501.10 (SCK), U502.10 (SCK), U503.10 (SCK), U602.10 (B4)
/SPI-CAN/SPI0_CLK_M2_1V8: U602.5 (A4); also elsewhere on the board
/SPI-CAN/SPI0_CS0: U501.13 (~CS); also elsewhere on the board
/SPI-CAN/SPI0_CS1: U502.13 (~CS); also elsewhere on the board
/SPI-CAN/SPI0_INT0: U501.4 (~INT); also elsewhere on the board
/SPI-CAN/SPI0_INT1: U502.4 (~INT); also elsewhere on the board
/SPI-CAN/SPI0_MISO_M2_1V8: U602.3 (A2); also elsewhere on the board
/SPI-CAN/SPI0_MOSI_M2_1V8: U602.2 (A1); also elsewhere on the board
/SPI-CAN/SPI00_OSC_1: C601.1, U501.6 (OSC1), Y601.1
/SPI-CAN/SPI00_OSC_2: C602.1, U501.5 (OSC2), Y601.3
/SPI-CAN/SPI0_SI: U501.11 (SDI), U502.11 (SDI), U503.11 (SDI), U602.13 (B1)
/SPI-CAN/SPI0_SO: U501.12 (SDO), U502.12 (SDO), U503.12 (SDO), U602.12 (B2)
/SPI-CAN/SPI01_CAN+: J602.2, R604.1, U606.7 (CANH)
/SPI-CAN/SPI01_CAN-: J602.1, R604.2, U606.6 (CANL)
/SPI-CAN/SPI01_OSC_1: C605.1, U502.6 (OSC1), Y602.1
/SPI-CAN/SPI01_OSC_2: C607.1, U502.5 (OSC2), Y602.3
/SPI-CAN/SPI02_CAN+: J603.2, R605.1, U607.7 (CANH)
/SPI-CAN/SPI02_CAN-: J603.1, R605.2, U607.6 (CANL)
/SPI-CAN/SPI02_OSC_1: C606.1, U503.6 (OSC1), Y603.1
/SPI-CAN/SPI02_OSC_2: C608.1, U503.5 (OSC2), Y603.3
GND: C601.2, C602.2, C603.2, C604.2, C605.2, C606.2, C607.2, C608.2, R602.1, U501.7 (VSS), U501.15 (VSS), U502.7 (VSS), U502.15 (VSS), U503.7 (VSS), U503.15 (VSS), U602.7 (GND), U603.2 (GND), U603.8 (Rs), U606.2 (GND), U606.8 (Rs), U607.2 (GND), U607.8 (Rs), Y601.2, Y601.4, Y602.2, Y602.4, Y603.2, Y603.4; also elsewhere on the board
unnamed: U501.2 (RXCAN), U603.4 (R)
unnamed: U501.1 (TXCAN), U603.1 (D)
unnamed: U502.2 (RXCAN), U606.4 (R)
unnamed: U502.1 (TXCAN), U606.1 (D)
unnamed: U503.2 (RXCAN), U607.4 (R)
unnamed: U503.1 (TXCAN), U607.1 (D)

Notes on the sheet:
C_L = (C**2 / 2C) + C_S C_L = load capacitance C_S = stray capacitance C = decoupling capacitance Assume C_L = 15p, C_S = 5p, 2C * 10p = C**2 20p * C = C**2 C = 20p Choosing 20p, closest value available

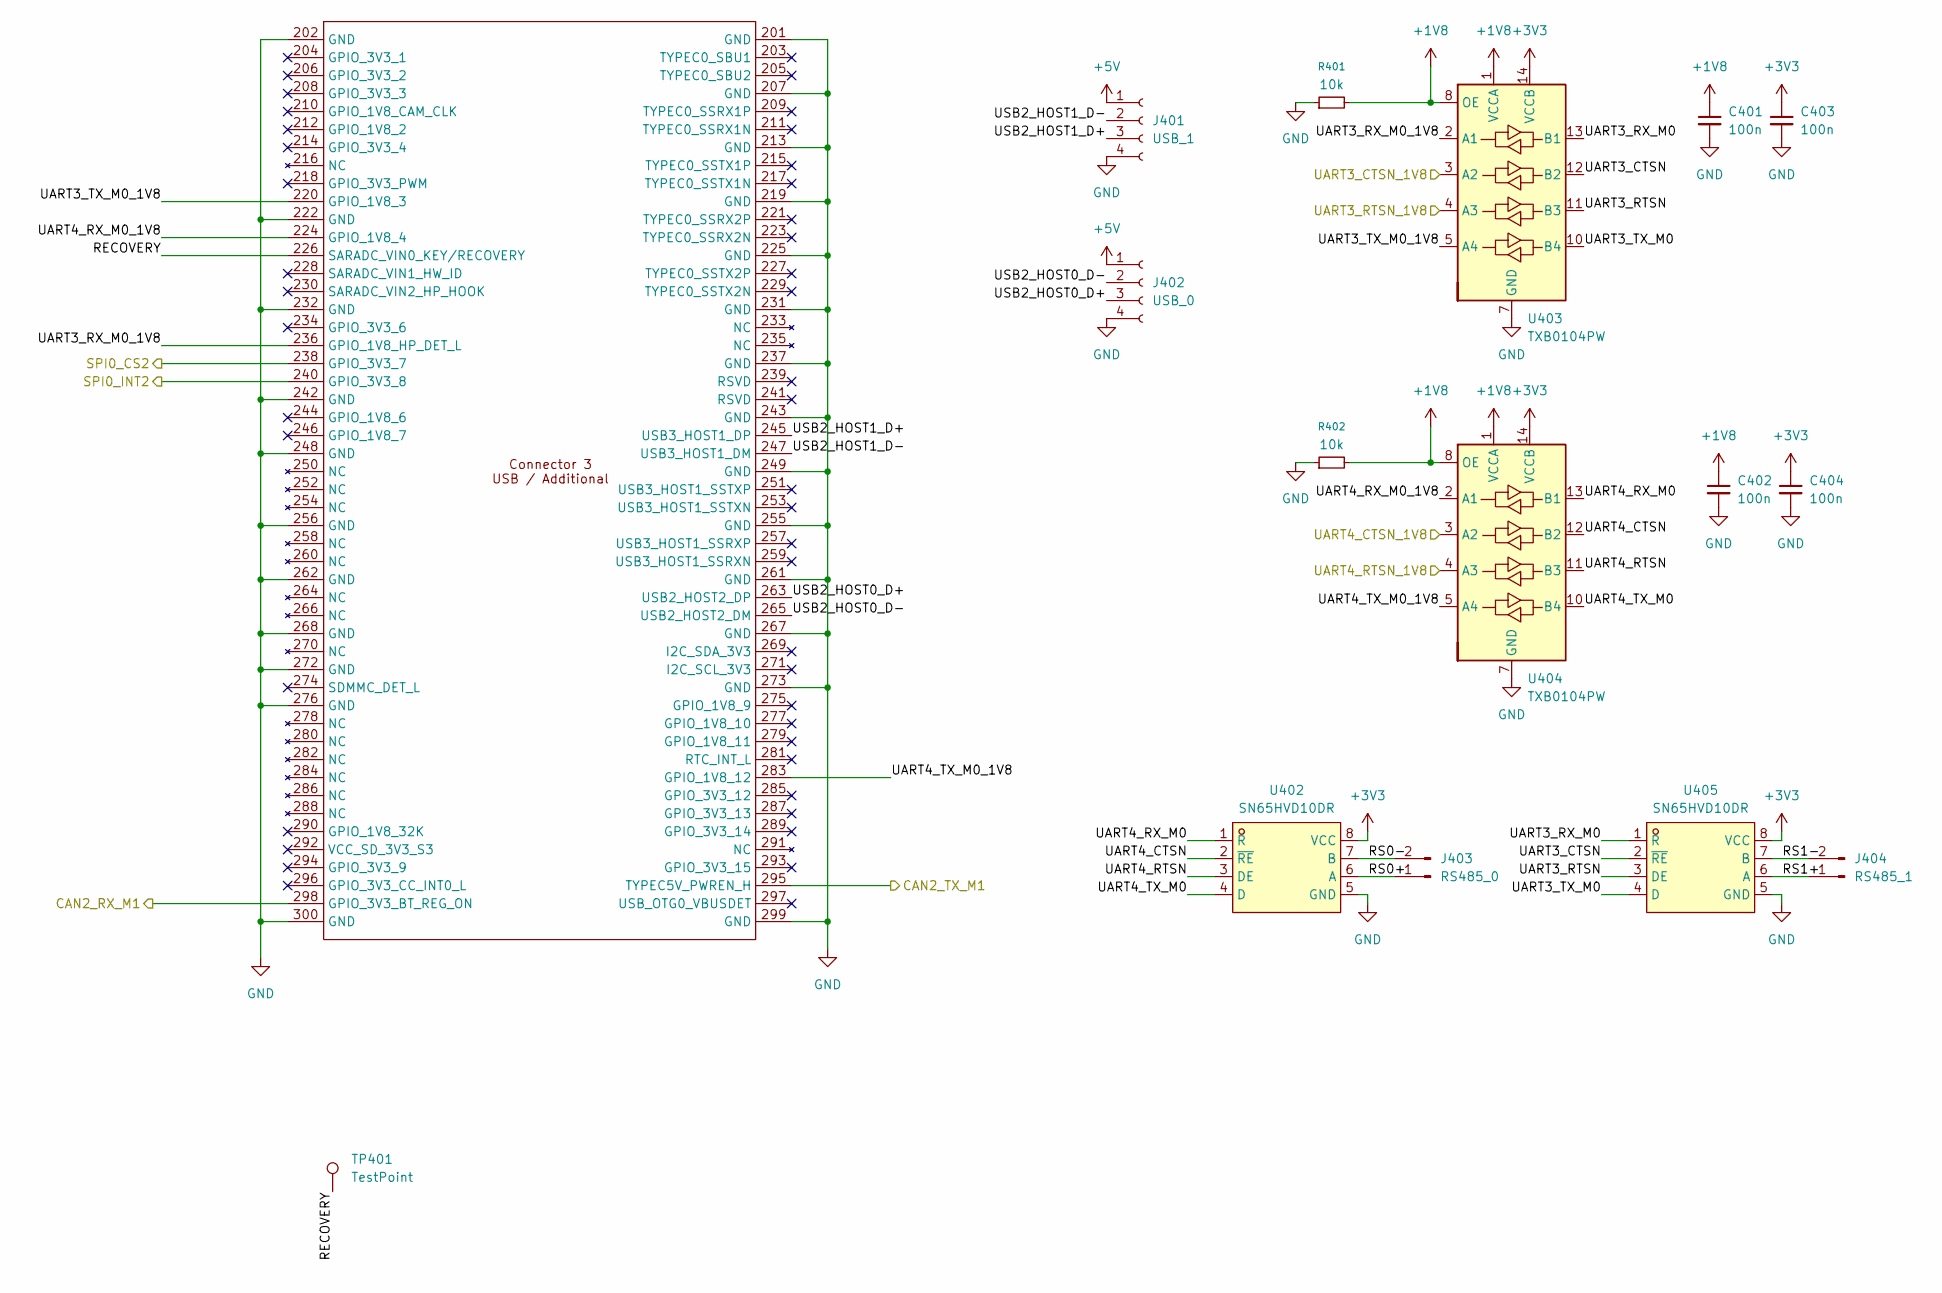
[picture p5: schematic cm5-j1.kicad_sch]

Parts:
C401, C402, C403, C404: 100n; C_0402_1005Metric; LCSC C77020
J401: USB_1; JST_GH_SM04B-GHS-TB_1x04-1MP_P1.25mm_Horizontal; LCSC C51940118
J402: USB_0; JST_GH_SM04B-GHS-TB_1x04-1MP_P1.25mm_Horizontal; LCSC C51940118
J403: RS485_0; JST_GH_SM02B-GHS-TB_1x02-1MP_P1.25mm_Horizontal; LCSC C189893
J404: RS485_1; JST_GH_SM02B-GHS-TB_1x02-1MP_P1.25mm_Horizontal; LCSC C189893
R401, R402: 10k; R_0402_1005Metric; LCSC C190095
TP401: TestPoint; TestPoint_Pad_D1.0mm
U401: Hirose DF40C-100DS-0.4V; radxa_cm5_3; LCSC C597931
U402, U405: SN65HVD10DR; SOIC-8_L4.9-W3.9-P1.27-LS6.0-BL; LCSC Part C148982
U403, U404: TXB0104PW; TSSOP-14_4.4x5mm_P0.65mm; LCSC C60708

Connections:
+1V8: C401.1, C402.1, R401.2, R402.2, U403.1 (VCCA), U403.8 (OE), U404.1 (VCCA), U404.8 (OE); also elsewhere on the board
+3V3: C403.1, C404.1, U402.8 (VCC), U403.14 (VCCB), U404.14 (VCCB), U405.8 (VCC); also elsewhere on the board
+5V: J401.1, J402.1; also elsewhere on the board
/CAN/RXCAN2: U401.298 (GPIO_3V3_BT_REG_ON); also elsewhere on the board
/CAN/TXCAN2: U401.295 (TYPEC5V_PWREN_H); also elsewhere on the board
/J1/RECOVERY: TP401.1, U401.226 (SARADC_VIN0_KEY/RECOVERY)
/J1/RS0+: J403.1, U402.6 (A)
/J1/RS0-: J403.2, U402.7 (B)
/J1/RS1+: J404.1, U405.6 (A)
/J1/RS1-: J404.2, U405.7 (B)
/J1/SPI0_CS2: U401.238 (GPIO_3V3_7); also elsewhere on the board
/J1/SPI0_INT2: U401.240 (GPIO_3V3_8); also elsewhere on the board
/J1/UART3_CTSN: U403.12 (B2), U405.2 (~RE)
/J1/UART3_CTSN_1V8: U403.3 (A2); also elsewhere on the board
/J1/UART3_RTSN: U403.11 (B3), U405.3 (DE)
/J1/UART3_RTSN_1V8: U403.4 (A3); also elsewhere on the board
/J1/UART3_RX_M0: U403.13 (B1), U405.1 (R)
/J1/UART3_RX_M0_1V8: U401.236 (GPIO_1V8_HP_DET_L), U403.2 (A1)
/J1/UART3_TX_M0: U403.10 (B4), U405.4 (D)
/J1/UART3_TX_M0_1V8: U401.220 (GPIO_1V8_3), U403.5 (A4)
/J1/UART4_CTSN: U402.2 (~RE), U404.12 (B2)
/J1/UART4_CTSN_1V8: U404.3 (A2); also elsewhere on the board
/J1/UART4_RTSN: U402.3 (DE), U404.11 (B3)
/J1/UART4_RTSN_1V8: U404.4 (A3); also elsewhere on the board
/J1/UART4_RX_M0: U402.1 (R), U404.13 (B1)
/J1/UART4_RX_M0_1V8: U401.224 (GPIO_1V8_4), U404.2 (A1)
/J1/UART4_TX_M0: U402.4 (D), U404.10 (B4)
/J1/UART4_TX_M0_1V8: U401.283 (GPIO_1V8_12), U404.5 (A4)
/J1/USB2_HOST0_D+: J402.3, U401.263 (USB2_HOST2_DP)
/J1/USB2_HOST0_D-: J402.2, U401.265 (USB2_HOST2_DM)
/J1/USB2_HOST1_D+: J401.3, U401.245 (USB3_HOST1_DP)
/J1/USB2_HOST1_D-: J401.2, U401.247 (USB3_HOST1_DM)
GND: C401.2, C402.2, C403.2, C404.2, J401.4, J402.4, R401.1, R402.1, U401.201 (GND), U401.202 (GND), U401.207 (GND), U401.213 (GND), U401.219 (GND), U401.222 (GND), U401.225 (GND), U401.231 (GND), U401.232 (GND), U401.237 (GND), U401.242 (GND), U401.243 (GND), U401.248 (GND), U401.249 (GND), U401.255 (GND), U401.256 (GND), U401.261 (GND), U401.262 (GND), U401.267 (GND), U401.268 (GND), U401.272 (GND), U401.273 (GND), U401.276 (GND), U401.299 (GND), U401.300 (GND), U402.5 (GND), U403.7 (GND), U404.7 (GND), U405.5 (GND); also elsewhere on the board

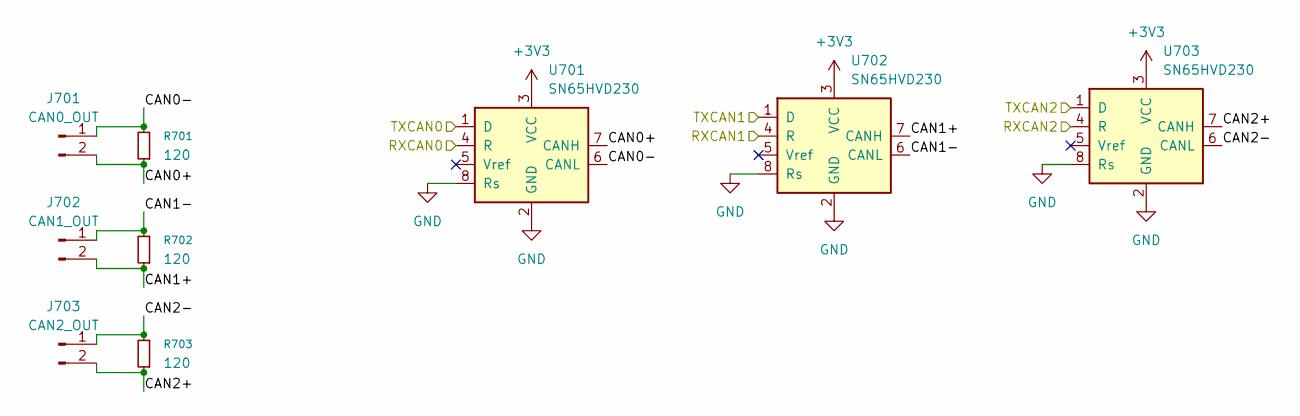
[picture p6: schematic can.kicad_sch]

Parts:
J701: CAN0_OUT; JST_GH_SM02B-GHS-TB_1x02-1MP_P1.25mm_Horizontal; LCSC C189893
J702: CAN1_OUT; JST_GH_SM02B-GHS-TB_1x02-1MP_P1.25mm_Horizontal; LCSC C189893
J703: CAN2_OUT; JST_GH_SM02B-GHS-TB_1x02-1MP_P1.25mm_Horizontal; LCSC C189893
R701, R702, R703: 120; R_0402_1005Metric; LCSC C114758
U701, U702, U703: SN65HVD230; SOIC-8_3.9x4.9mm_P1.27mm; LCSC C12084

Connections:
+3V3: U701.3 (VCC), U702.3 (VCC), U703.3 (VCC); also elsewhere on the board
/CAN/CAN0+: J701.2, R701.1, U701.7 (CANH)
/CAN/CAN0-: J701.1, R701.2, U701.6 (CANL)
/CAN/CAN1+: J702.2, R702.1, U702.7 (CANH)
/CAN/CAN1-: J702.1, R702.2, U702.6 (CANL)
/CAN/CAN2+: J703.2, R703.1, U703.7 (CANH)
/CAN/CAN2-: J703.1, R703.2, U703.6 (CANL)
/CAN/RXCAN0: U701.4 (R); also elsewhere on the board
/CAN/RXCAN1: U702.4 (R); also elsewhere on the board
/CAN/RXCAN2: U703.4 (R); also elsewhere on the board
/CAN/TXCAN0: U701.1 (D); also elsewhere on the board
/CAN/TXCAN1: U702.1 (D); also elsewhere on the board
/CAN/TXCAN2: U703.1 (D); also elsewhere on the board
GND: U701.2 (GND), U701.8 (Rs), U702.2 (GND), U702.8 (Rs), U703.2 (GND), U703.8 (Rs); also elsewhere on the board

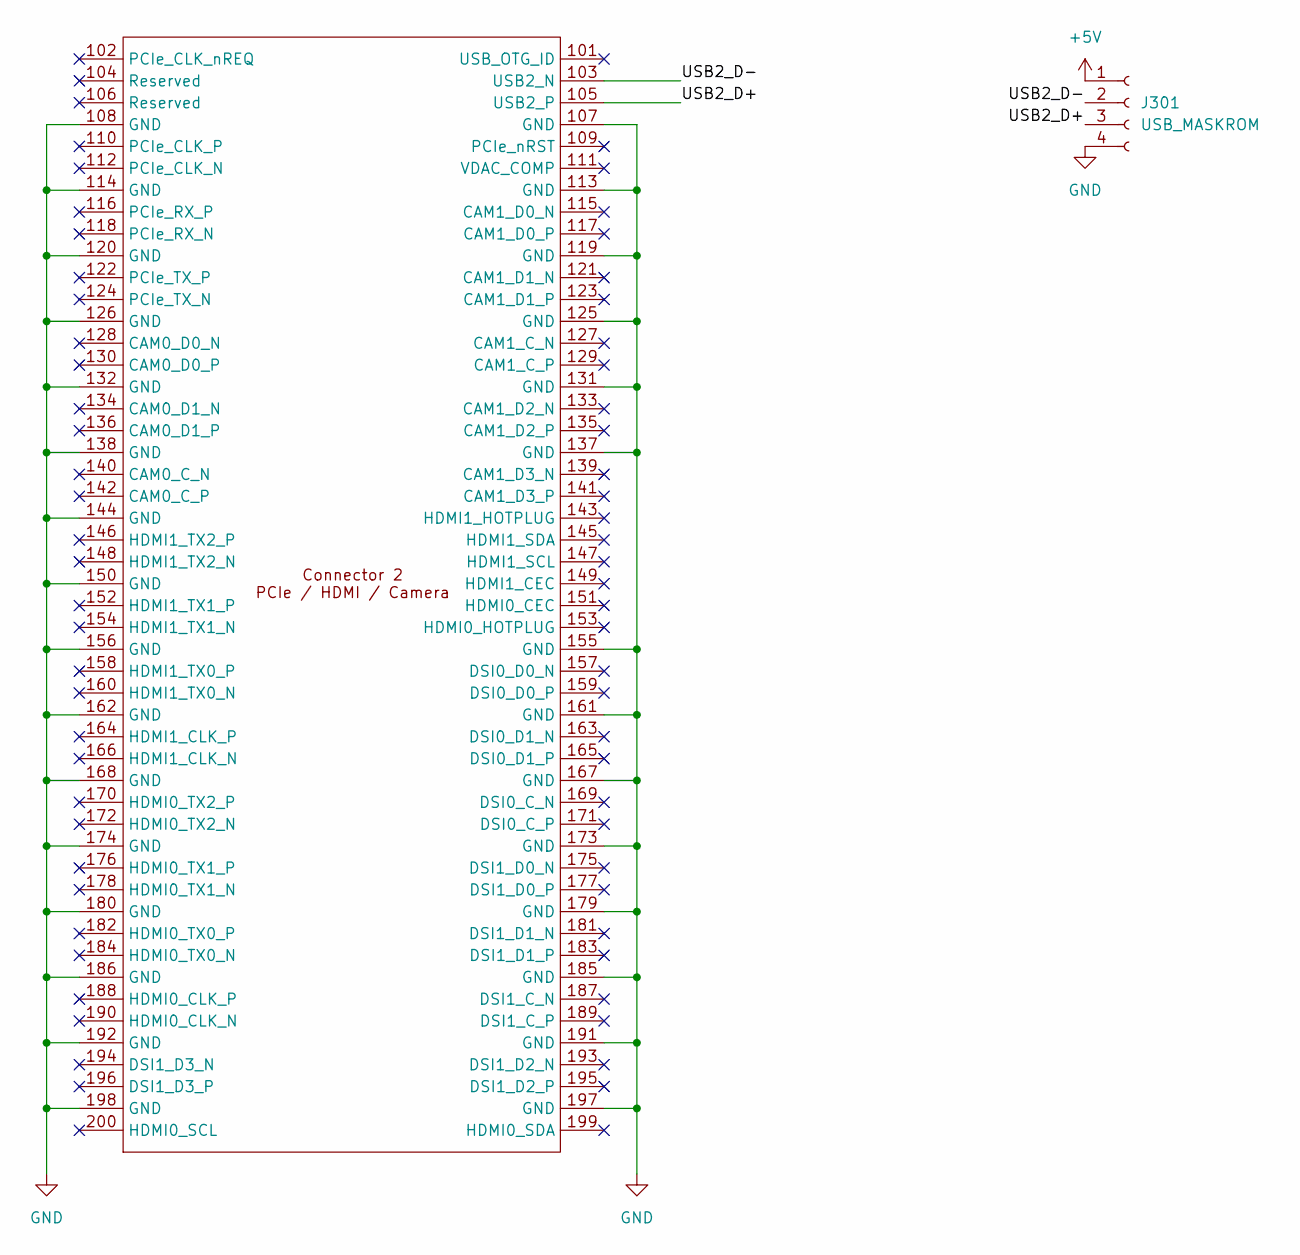
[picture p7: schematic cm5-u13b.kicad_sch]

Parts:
J301: USB_MASKROM; JST_GH_SM04B-GHS-TB_1x04-1MP_P1.25mm_Horizontal; LCSC C51940118
U301: Hirose DF40C-100DS-0.4V; radxa_cm5_2; LCSC C597931

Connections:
+5V: J301.1; also elsewhere on the board
/U13B/USB2_D+: J301.3, U301.105 (USB2_P)
/U13B/USB2_D-: J301.2, U301.103 (USB2_N)
GND: J301.4, U301.107 (GND), U301.108 (GND), U301.113 (GND), U301.114 (GND), U301.119 (GND), U301.120 (GND), U301.125 (GND), U301.126 (GND), U301.131 (GND), U301.132 (GND), U301.137 (GND), U301.138 (GND), U301.144 (GND), U301.150 (GND), U301.155 (GND), U301.156 (GND), U301.161 (GND), U301.162 (GND), U301.167 (GND), U301.168 (GND), U301.173 (GND), U301.174 (GND), U301.179 (GND), U301.180 (GND), U301.185 (GND), U301.186 (GND), U301.191 (GND), U301.192 (GND), U301.197 (GND), U301.198 (GND); also elsewhere on the board

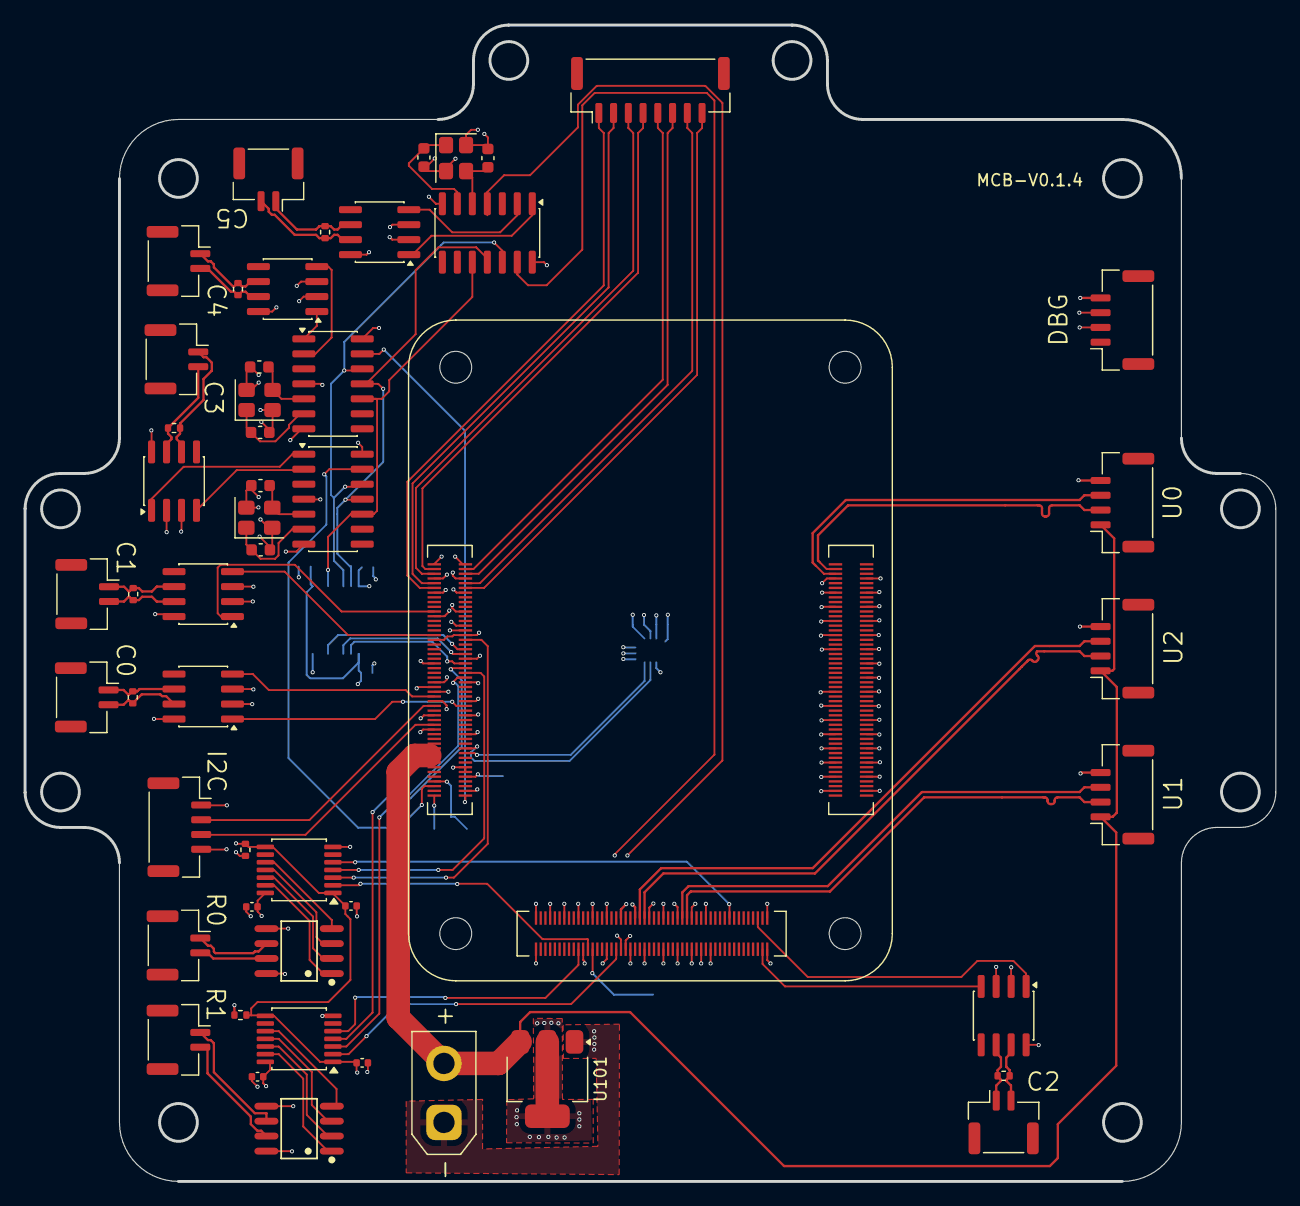
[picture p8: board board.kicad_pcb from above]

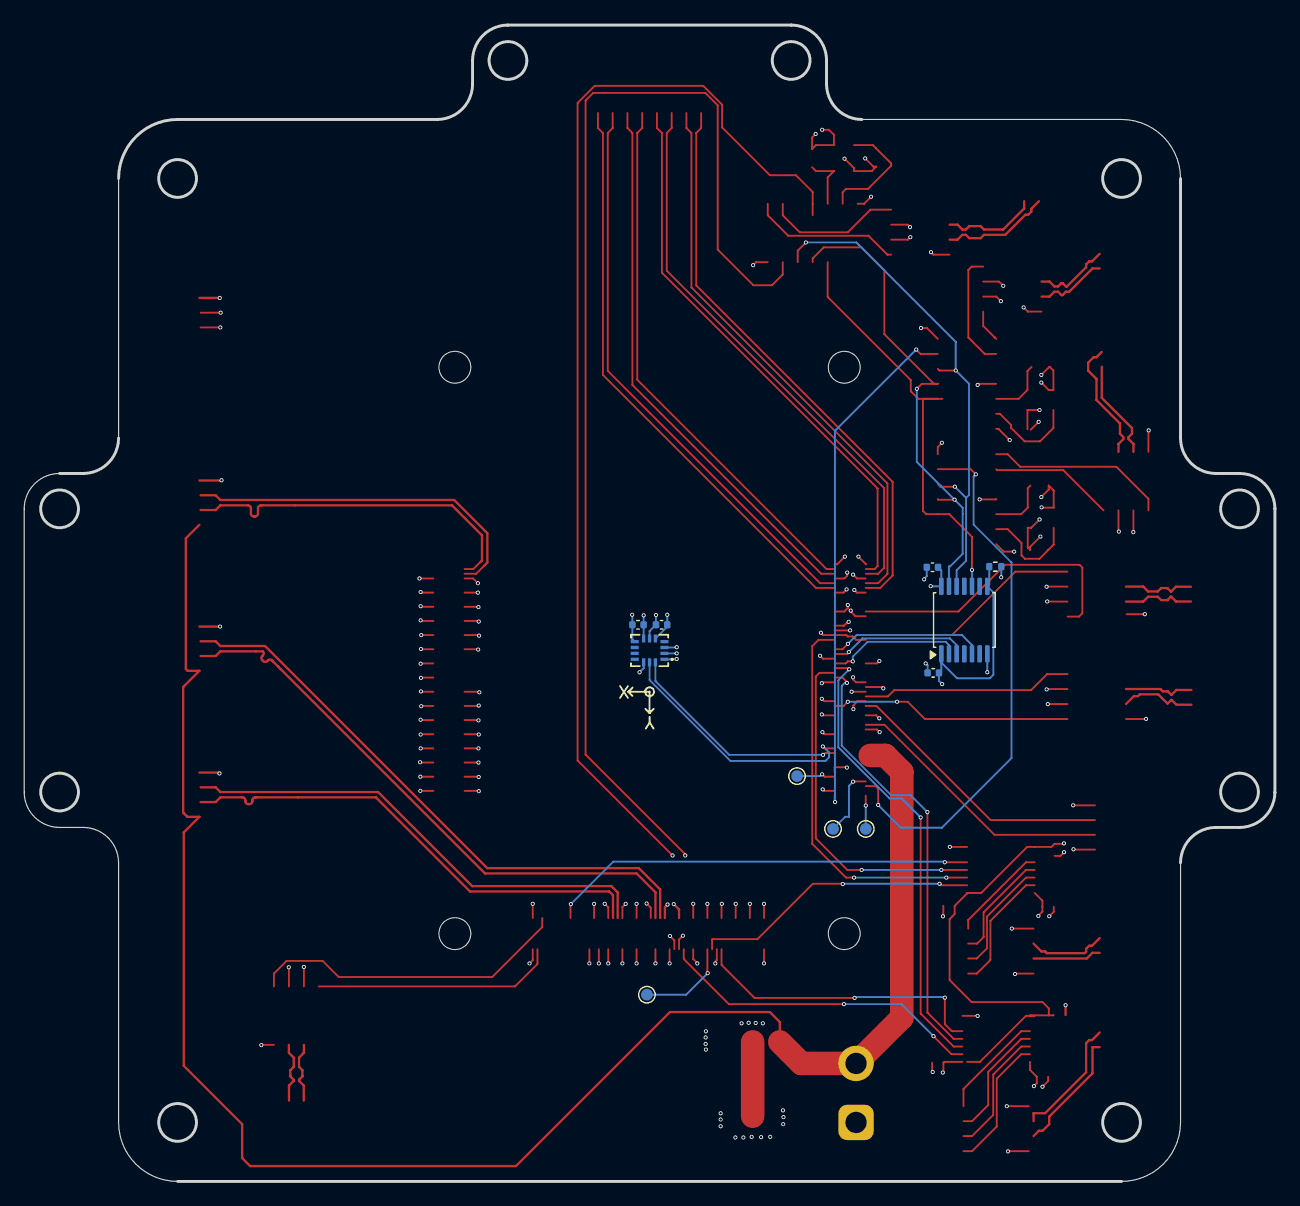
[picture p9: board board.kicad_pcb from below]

Board: 4 copper layers, 106.0 x 98.0 mm, 64 parts (11 on the bottom side), 90 nets.

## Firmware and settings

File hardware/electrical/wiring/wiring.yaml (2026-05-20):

connectors:
  "Left Ankle A":
    type: "XT30(2+2)"
    subtype: female
    pinlabels: [BATT+, BATT-, CAN_H, CAN_L]
  "Left Ankle B":
    type: "XT30(2+2)"
    subtype: female
    pinlabels: [BATT+, BATT-, CAN_H, CAN_L]
  "Left Knee":
    type: "XT30(2+2)"
    subtype: female
    pinlabels: [BATT+, BATT-, CAN_H, CAN_L]
  "Left Hip Pitch":
    type: "XT30(2+2)"
    subtype: female
    pinlabels: [BATT+, BATT-, CAN_H, CAN_L]
  "Left Hip Roll":
    type: "XT30(2+2)"
    subtype: female
    pinlabels: [BATT+, BATT-, CAN_H, CAN_L]
  "Left Hip Yaw":
    type: "XT30(2+2)"
    subtype: female
    pinlabels: [BATT+, BATT-, CAN_H, CAN_L]
  "Right Ankle A":
    type: "XT30(2+2)"
    subtype: female
    pinlabels: [BATT+, BATT-, CAN_H, CAN_L]
  "Right Ankle B":
    type: "XT30(2+2)"
    subtype: female
    pinlabels: [BATT+, BATT-, CAN_H, CAN_L]
  "Right Knee":
    type: "XT30(2+2)"
    subtype: female
    pinlabels: [BATT+, BATT-, CAN_H, CAN_L]
  "Right Hip Pitch":
    type: "XT30(2+2)"
    subtype: female
    pinlabels: [BATT+, BATT-, CAN_H, CAN_L]
  "Right Hip Roll":
    type: "XT30(2+2)"
    subtype: female
    pinlabels: [BATT+, BATT-, CAN_H, CAN_L]
  "Right Hip Yaw":
    type: "XT30(2+2)"
    subtype: female
    pinlabels: [BATT+, BATT-, CAN_H, CAN_L]
  "BMS":
    subtype: soldered
    pinlabels: [CAN_H, CAN_L]
  "BMS Root SIG":
    type: "MOLEX KK 254 2 pin"
    subtype: female
    pinlabels: [CAN_H, CAN_L]
  "Neck Pitch":
    type: "XT30(2+2)"
    subtype: female
    pinlabels: [BATT+, BATT-, CAN_H, CAN_L]
  "Neck Yaw":
    type: "XT30(2+2)"
    subtype: female
    pinlabels: [BATT+, BATT-, CAN_H, CAN_L]
  "Left Shoulder Pitch":
    type: "XT30(2+2)"
    subtype: female
    pinlabels: [BATT+, BATT-, CAN_H, CAN_L]
  "Left Shoulder Roll":
    type: "XT30(2+2)"
    subtype: female
    pinlabels: [BATT+, BATT-, CAN_H, CAN_L]
  "Left Shoulder Yaw":
    type: "XT30(2+2)"
    subtype: female
    pinlabels: [BATT+, BATT-, CAN_H, CAN_L]
  "Left Elbow":
    type: "XT30(2+2)"
    subtype: female
    pinlabels: [BATT+, BATT-, CAN_H, CAN_L]
  "Left Wrist Yaw":
    type: "XT30(2+2)"
    subtype: female
    pinlabels: [BATT+, BATT-, CAN_H, CAN_L]
  "Right Shoulder Pitch":
    type: "XT30(2+2)"
    subtype: female
    pinlabels: [BATT+, BATT-, CAN_H, CAN_L]
  "Right Shoulder Roll":
    type: "XT30(2+2)"
    subtype: female
    pinlabels: [BATT+, BATT-, CAN_H, CAN_L]
  "Right Shoulder Yaw":
    type: "XT30(2+2)"
    subtype: female
    pinlabels: [BATT+, BATT-, CAN_H, CAN_L]
  "Right Elbow":
    type: "XT30(2+2)"
    subtype: female
    pinlabels: [BATT+, BATT-, CAN_H, CAN_L]
  "Right Wrist Yaw":
    type: "XT30(2+2)"
    subtype: female
    pinlabels: [BATT+, BATT-, CAN_H, CAN_L]
  "Waist Yaw":
    type: "XT30(2+2)"
    subtype: female
    pinlabels: [BATT+, BATT-, CAN_H, CAN_L]
  "Left Leg Root SIG":
    type: "MOLEX KK 254 2 pin"
    subtype: female
    pinlabels: [CAN_H, CAN_L]
  "Right Leg Root SIG":
    type: "MOLEX KK 254 2 pin"
    subtype: female
    pinlabels: [CAN_H, CAN_L]
  "Lower Body PWR":
    type: "XT-30"
    subtype: female
    pinlabels: [BATT+, BATT-]
  "Left Arm PWR":
    type: "XT-30"
    subtype: female
    pinlabels: [BATT+, BATT-]
  "Right Arm PWR":
    type: "XT-30"
    subtype: female
    pinlabels: [BATT+, BATT-]
  "Neck-Waist PWR":
    type: "XT-30"
    subtype: female
    pinlabels: [BATT+, BATT-]
  "Left Arm Root SIG":
    type: "MOLEX KK 254 2 pin"
    subtype: female
    pinlabels: [CAN_H, CAN_L]
  "Right Arm Root SIG":
    type: "MOLEX KK 254 2 pin"
    subtype: female
    pinlabels: [CAN_H, CAN_L]
  "Neck-Waist Link 1":
    type: "MOLEX KK 254 2 pin"
    subtype: female
    pinlabels: [CAN_H, CAN_L]
  "Neck-Waist Root SIG":
    type: "MOLEX KK 254 2 pin"
    subtype: female
    pinlabels: [CAN_H, CAN_L]
  "Neck-Waist Link 2":
    type: "MOLEX KK 254 2 pin"
    subtype: female
    pinlabels: [CAN_H, CAN_L]
  "BMS Power":
    type: "XT-60"
    subtype: female
    pinlabels: [BATT+, BATT-]
  "BMS Power Sink":
    type: "XT-30"
    subtype: female
    pinlabels: [BATT+, BATT-]
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

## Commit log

2026-05-14 The framework of the body
    [IMU_ORIGIN.STL, LEFT_ANKLE_A.STL, LEFT_ANKLE_B.STL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]
2026-05-15 Initial robot structure with head
    [ASIMOV_V1.STEP, ASV1_100.STEP, ASV1_100_01C.STEP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]
2026-05-15 Saving current state before LFS migration
2026-05-18 Complete robot shell ready
    [HEAD.STL, Hand.blend, LEFT_ELBOW.STL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]
2026-05-18 Hands orientation fixed, forearm upgraded
    [Hand.blend, RevExBotV1.blend, forearm2.stl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]
2026-05-18 Fixed height of robot (increased), UPgraded and finalized the orientation
    [LEFT_HIP_YAW.STL, LEFT_KNEE.STL, LEFT_WRIST_YAW.STL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]
2026-05-19 Re-scaled down. Fixed and finalized the complete orientation
    [LEFT_HIP_YAW.STL, LEFT_KNEE.STL, RIGHT_HIP_YAW.STL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]
2026-05-20 UPgraded .xacro design and hands
    [LEFT_ELBOW.STL, LEFT_WRIST_YAW.STL, RIGHT_ELBOW.STL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]
2026-05-20 Added required files for phase 3- hardware development and existing RL configs for hands
    [ASIMOV_V1.STEP, ASV1_100.STEP, ASV1_100_01C.STEP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]
2026-05-20 Changed folder structure, added readme, finished phase 1.
    [board.kicad_sch, dip.stl, fingertip.stl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]
2026-05-20 Files rearranged. Started building RL config
    [FABRICATION_MANIFEST.csv, REVEXBOT_V1.STEP, RVX1_100.STEP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]
2026-05-28 Upgraded pipeline for AMP with SKRL, completed phase 3, Upgraded all phases in sync
    [RobotHandDefault.yaml, RobotHandDefaultPPO.yaml, faive_hand.xacro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]
2026-05-28 Updated weights and maths in the xacro blueprints
    [faive_hand.xacro, revexbot1.urdf]
2026-06-10 Hand changed.
    [F01_AL_link_hand.stl, F01_AL_link_hand_down.stl, F03_AL_link_DIP.stl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]
2026-06-10 Implemented combination of modified hands with body
    [F01_AL_link_hand.stl, F01_AL_link_hand_down.stl, F03_AL_link_DIP.stl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]
2026-06-10 Updated xacros for isaaclab
    [hri_hand.xacro, master_assembly.xacro, revexbot1.urdf]
